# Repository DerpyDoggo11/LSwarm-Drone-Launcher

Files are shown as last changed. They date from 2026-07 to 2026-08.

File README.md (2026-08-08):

# LS Mk.1 Drone Launcher
Compact drone launcher + central compute module

## 3D Model Preview
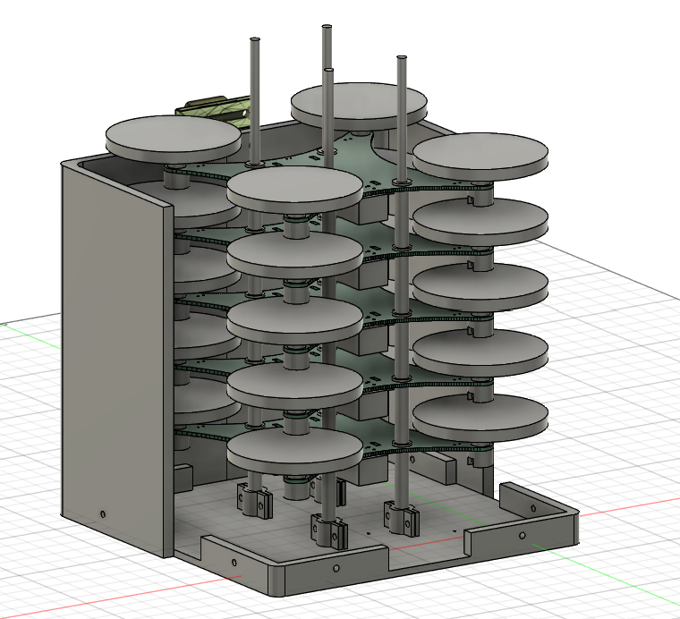
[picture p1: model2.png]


## 3D PCB Preview
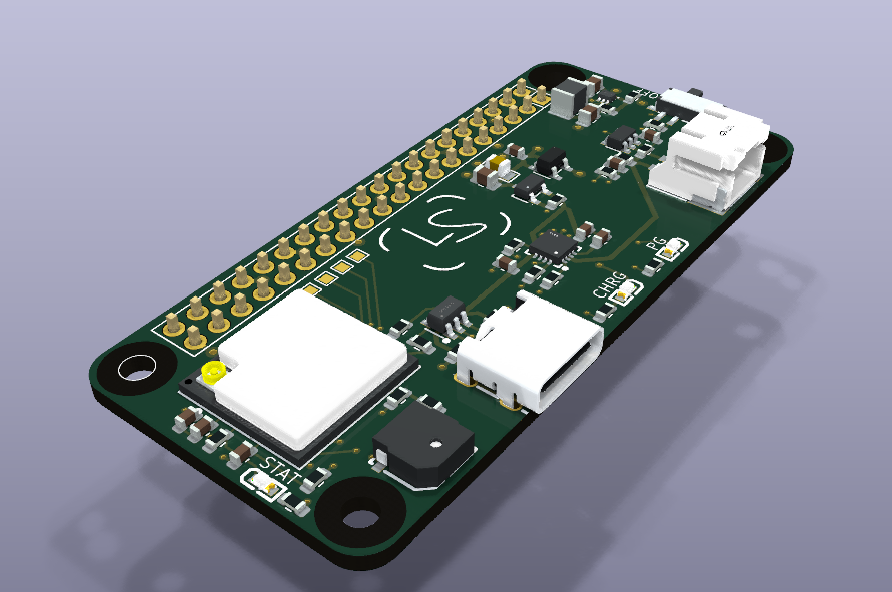
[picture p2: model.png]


## Wiring
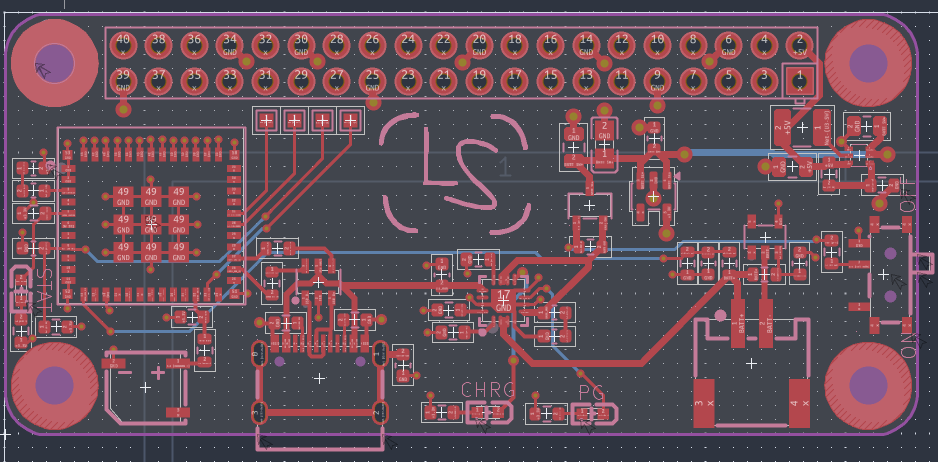
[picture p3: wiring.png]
PCB


## Schematic
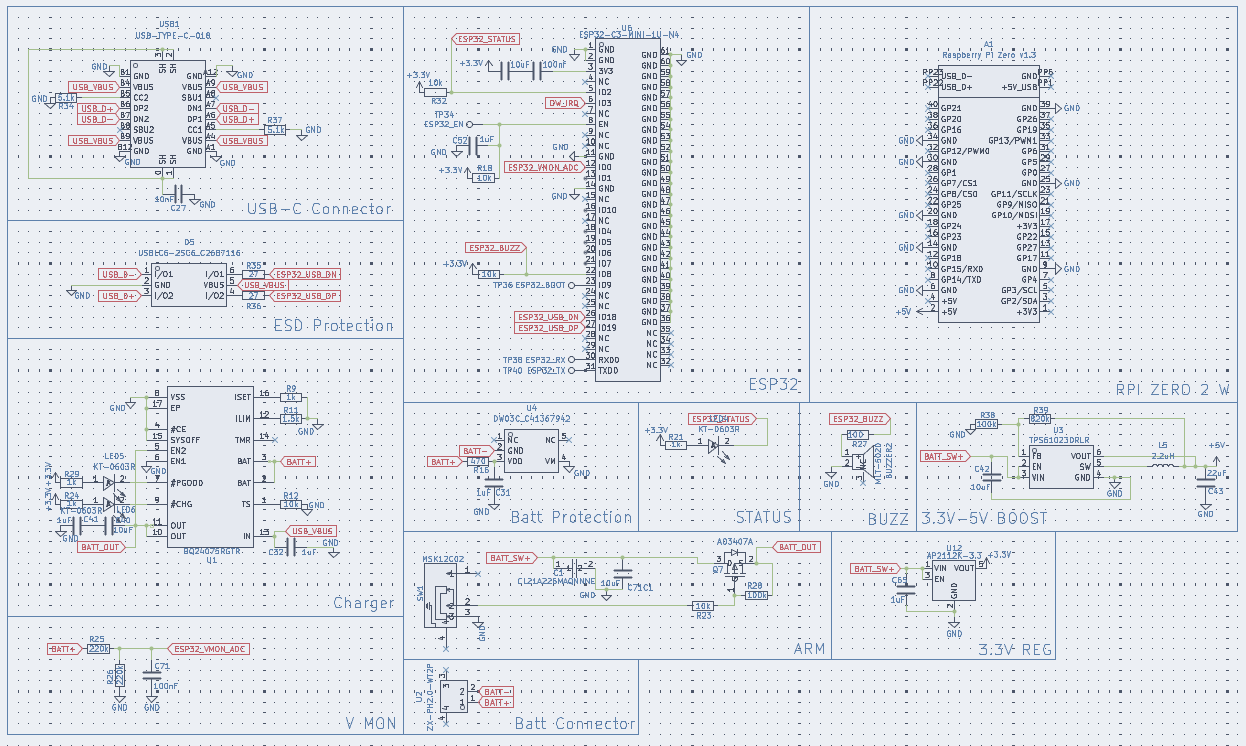
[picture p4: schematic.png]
Schematic


### Download ./latestProduction to begin fabricating the PCB

## Introduction
As a solution to needing to store tons of [these](https://forge.hackclub.com/projects/93) microdrones as well as the central compute unit, I designed a vertically mounting lift off platform and storage unit called the LS Mk.1 Drone Launcher. Its super modular so that it can be stacked on itself and easily stored in a grid and scale to any number of drones. The design is essentially a 3D printed platform with four metal rods for guiding the drones, the top and bottom half can separated or connected by opening or closing the latches. The platform currently has a capacity for 5 drones each.

For calculating and planning the trajectory of the drones, this launcher uses a Raspbbery Pi Zero 2 W along with a custom Pi hat. The custom Pi hat extends the wifi range of the Raspberry Pi Zero 2 W to communicate with the LS Anchors and adds a battery for independent usage from wall outlets. Only 1 compute module should be necessary per batch of launcher units.

## Bill of Materials 

### Minimum Build:

| Quantity | Components | Price | Link |
|--- |---|---| -----|
| 1  | Raspberry Pi Zero 2 W | ~15$ | [here](https://www.sparkfun.com/raspberry-pi-zero-2-w.html?src=raspberrypi)
| 1 | Clear PLA Filament | ~20$ | [here](https://www.amazon.com/SUNLU-Filament-Transparent-Dimensional-Accuracy/dp/B07ZNG4L9P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)
| 1 | 1200mAh Lipo Battery | ~20$ [here](https://www.aliexpress.us/item/3256811414820649.html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)
| 1 | 155mm Leather Handle | ~2$ | [here](https://www.aliexpress.us/item/3256812155687340.html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)
| 4 | 200mm x 4mm Metal Rods | $5 | [here](https://www.aliexpress.us/item/3256805290944526.html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)
| 1  | RPI Hat PCB | ~15$ | Download repo, extract fabrication files, and fabricate through JLCPCB (complete instructions for this may come soon)
| 1  | Electronic Components | ~30$ | See production BOM for a full list, the PCB fabrication files automatically include these components as well.
| 4 | 20mm M2.5 Bolts | $10 | Reference (can find it cheaper elsewhere): [here](https://www.mcmaster.com/products/91290a108/)
| 16 | 16mm M2.5 Bolts | $10 | Reference (can find it cheaper elsewhere): [here](https://www.mcmaster.com/products/91290A106/)
| 20 | M2.5 Nuts | $10 | Reference (can find it cheaper elsewhere): [here](https://www.mcmaster.com/products/90591a270/)

Total: ~$140

----

## Tools / Other parts:
- Hot air gun or hot plate
- Solder paste
- Tweazers
- Screwdriver

## Assembly
- Apply solder paste to all the solder pads
- Use tweazers to place components and reflow with hot air gun or hot plate
- Assemble control unit case and mount battery and antenna onto the pcb and raspbbery pi zero 2W
- Print all parts of the case
- Assemble the launcher case and latch together
- Print drone landing gears and mount them

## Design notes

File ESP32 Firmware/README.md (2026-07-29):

# ESP32-C3 Firmware — LSwarm Drone Launcher

Power/status co-processor that runs on the **ESP32-C3-MINI-1U-N4 (U6)** of the
Compute Hat. It measures the battery, watches the protection-IC fault line, and
drives the status LED and buzzer, exposing everything to the Raspberry Pi over
a USB-CDC line protocol.

## Hardware map (from the schematic)

| Function | GPIO | Notes |
|---|---|---|
| Status LED | 2 | Active-**low** (sinks from 3V3 via R21 1k). Boot strap. |
| DW03C fault | 3 | `DW_IRQ`, active-**low** input, internal pull-up. |
| Battery VMON  | 0 | ADC1_CH0, reads `BATT+ / 2` (R25 220k / R26 220k divider). |
| Buzzer | 8 | Active-**high**, MOSFET-driven MLT-5020, PWM tone. Strap. |
| Boot | 9 | Strap / test point — not driven by firmware. |

## Build / flash

```bash
pio run                 # build
pio run -t upload       # flash over the USB-C port
pio device monitor      # open the CDC serial monitor (115200)
```

## Link protocol

ASCII, one message per line (`\n`). Full definition in
[`include/protocol.h`](include/protocol.h) — kept identical to the Pi firmware.

**Pi → ESP32**

| Command | Effect |
|---|---|
| `PING` | replies `PONG` |
| `ID?` | replies `ID LSwarm-ESP32C3 fw=<ver>` |
| `STATUS?` | emits one `TELEM` frame immediately |
| `LED <mode>` | `off` `on` `blink` `beat` `sos` |
| `BUZZ <hz> <ms>` | play a tone for `<ms>` (`0` = stop) |
| `BEEP <count>` | N short feedback beeps |
| `TELEM <period_ms>`| set auto-telemetry period (`0` = off) |

**ESP32 → Pi**

| Message | When |
|---|---|
| `RDY <ver>` | once at boot |
| `TELEM v=<mV> soc=<pct> fault=<0/1> up=<ms>` | periodic / on `STATUS?` |
| `EVT fault=<0/1>` | on a DW_IRQ edge |
| `OK <cmd>` / `ERR <reason>` / `PONG` | command replies |

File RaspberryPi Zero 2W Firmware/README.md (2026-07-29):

# Raspberry Pi Zero 2 W Firmware — LSwarm Drone Launcher

The **central compute** node. The Pi Zero 2 W is a Linux SBC, so this is a
PlatformIO `native` C++ project written in the same Arduino `setup()`/`loop()`
style as the ESP32 firmware — a small Linux shim
([`include/arduino_compat.h`](include/arduino_compat.h)) provides `millis()`,
`delay()`, and a `Serial`-like port over the USB-CDC link.

Today it owns the link to the ESP32 co-processor (battery/fault telemetry,
LED/buzzer commands, keep-alive) and forwards operator input. Swarm / Wi-Fi
coordination logic builds on top of `loop()` in [`src/main.cpp`](src/main.cpp).

## How it connects

The ESP32-C3 native USB is shared with the Pi's USB-OTG lines on the USB-C
port, so the co-processor enumerates on the Pi as **`/dev/ttyACM0`**. The wire
protocol is defined in [`include/protocol.h`](include/protocol.h) (identical to
the ESP32's copy).

## Build & run

```bash
# On the Pi (or any Linux host), with PlatformIO Core:
pio run                                   # -> .pio/build/pizero/program
.pio/build/pizero/program                 # default: /dev/ttyACM0 @ 115200
.pio/build/pizero/program /dev/ttyACM1    # override port/baud

# Or straight from g++ if you'd rather skip PlatformIO:
g++ -std=c++17 -O2 -Iinclude src/*.cpp -o program
```

Add your user to the `dialout` group for serial access:
`sudo usermod -aG dialout $USER` (re-login after).

Run it as a service with the included [`lswarm-compute.service`](lswarm-compute.service).

## Using it

While running, type a command and press Enter — it goes straight to the ESP32:

```
LED blink          # status LED pattern: off | on | blink | beat | sos
BEEP 2             # two feedback beeps
BUZZ 2700 300      # 2.7 kHz tone for 300 ms
STATUS?            # request one telemetry frame
TELEM 500          # set auto-telemetry to 500 ms (0 = off)
quit               # exit
```

Incoming telemetry is printed live, e.g.
`[   12345] BATT 4013 mV  soc=79%  fault=0`.

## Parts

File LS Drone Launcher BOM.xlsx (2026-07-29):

Quantity | Component | Price | Link
1 | Raspberry Pi Zero 2W | $15 | https://www.sparkfun.com/raspberry-pi-zero-2-w.html?src=raspberrypi
1 | Clear PLA Filament | $20
1 | 1200mAh Lipo | $10 | https://www.aliexpress.us/item/3256811414820649.html?curPageLogUid=uhXJ9YqKgNaO
1 | 155mm Leather Handle | $2 | https://www.aliexpress.us/item/3256812155687340.html?curPageLogUid=BP5HyM53Apva
4 | 200mm x 4mm Metal Rods | $5 | https://www.aliexpress.us/item/3256805290944526.html?curPageLogUid=mLtoWIDfhah6
1 | Custom RPI Hat PCB | $15 | Download repo, extract fabrication files, and fabricate through JLCPCB (complete instructions for this may come soon)
1 | PCB Electronics | $30 | See production BOM for a full list, the PCB fabrication files automatically include these components as well.
Total | ~$100

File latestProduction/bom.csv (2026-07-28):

Designator | Footprint | Quantity | Value | LCSC Part #
A1 | RASPI_ZERO_FULL | 1 | Raspberry Pi Zero v1.3
BUZZER2 | BUZ-SMD_L5.0-W5.5-P4.60 | 1 | MLT-5020 | C94598
C1 | C0805 | 1 | CL21A226MAQNNNE | C45783
C27 | 0603 | 1 | 10nF
C31, C32, C41, C52, C65 | 0603 | 5 | 1uF
C40, C55 | 0603 | 2 | 10uF
C42, C71C1 | 0805 | 2 | 10uF
C43 | 0805 | 1 | 22uF
C56, C71 | 0603 | 2 | 100nf
D5 | SOT-23-6_L2.9-W1.6-P0.95-LS2.8-BL | 1 | USBLC6-2SC6_C2687116 | C2687116
L5 | 1210 | 1 | 2.2uH
LED4, LED5, LED6 | LED-SMD_L1.6-W0.8-R-RD | 3 | KT-0603R | C2286
Q7 | SOT-23-3_L2.9-W1.6-P1.90-LS2.8-BR | 1 | AO3407A | C15155
R11 | 0603 | 1 | 1.5k
R12, R18, R23, R32, R33 | 0603 | 5 | 10k
R16 | 0603 | 1 | 470
R21, R24, R29, R9 | 0603 | 4 | 1k
R25, R26 | 0603 | 2 | 220k
R27 | 0603 | 1 | 100
R28, R38 | 0603 | 2 | 100k
R34, R37 | 0603 | 2 | 5.1k
R35, R36 | 0603 | 2 | 27
R39 | 0603 | 1 | 820k
SW1 | SW-TH_MSK12C02 | 1 | MSK12C02 | C431540
TP34 | TestPoint_Pad_1.0x1.0mm | 1 | ESP32_EN
TP36 | TestPoint_Pad_1.0x1.0mm | 1 | ESP32_BOOT
TP38 | TestPoint_Pad_1.0x1.0mm | 1 | ESP32_RX
TP40 | TestPoint_Pad_1.0x1.0mm | 1 | ESP32_TX
U1 | QFN-16_L3.0-W3.0-P0.50-TL-EP1.7 | 1 | BQ24075RGTR | C15464
U12 | SOT-23-5 | 1 | AP2112K-3.3
U2 | CONN-SMD_ZX-PH2.0-WT2P | 1 | ZX-PH2.0-WT2P | C7429689
U3 | SOT-563_L1.6-W1.2-P0.50-LS1.6-BR | 1 | TPS61023DRLR | C919459
U4 | SOT-23-5_L2.9-W1.6-P0.95-LS2.9-BL | 1 | DW03C_C41367942 | C41367942
U6 | WIFIM-SMD_61P-L13.2-W12.5-P0.80 | 1 | ESP32-C3-MINI-1U-N4 | C2911374
USB1 | USB-C_SMD-TYPE-C-31-M-12 | 1 | USB-TYPE-C-018 | C2927038

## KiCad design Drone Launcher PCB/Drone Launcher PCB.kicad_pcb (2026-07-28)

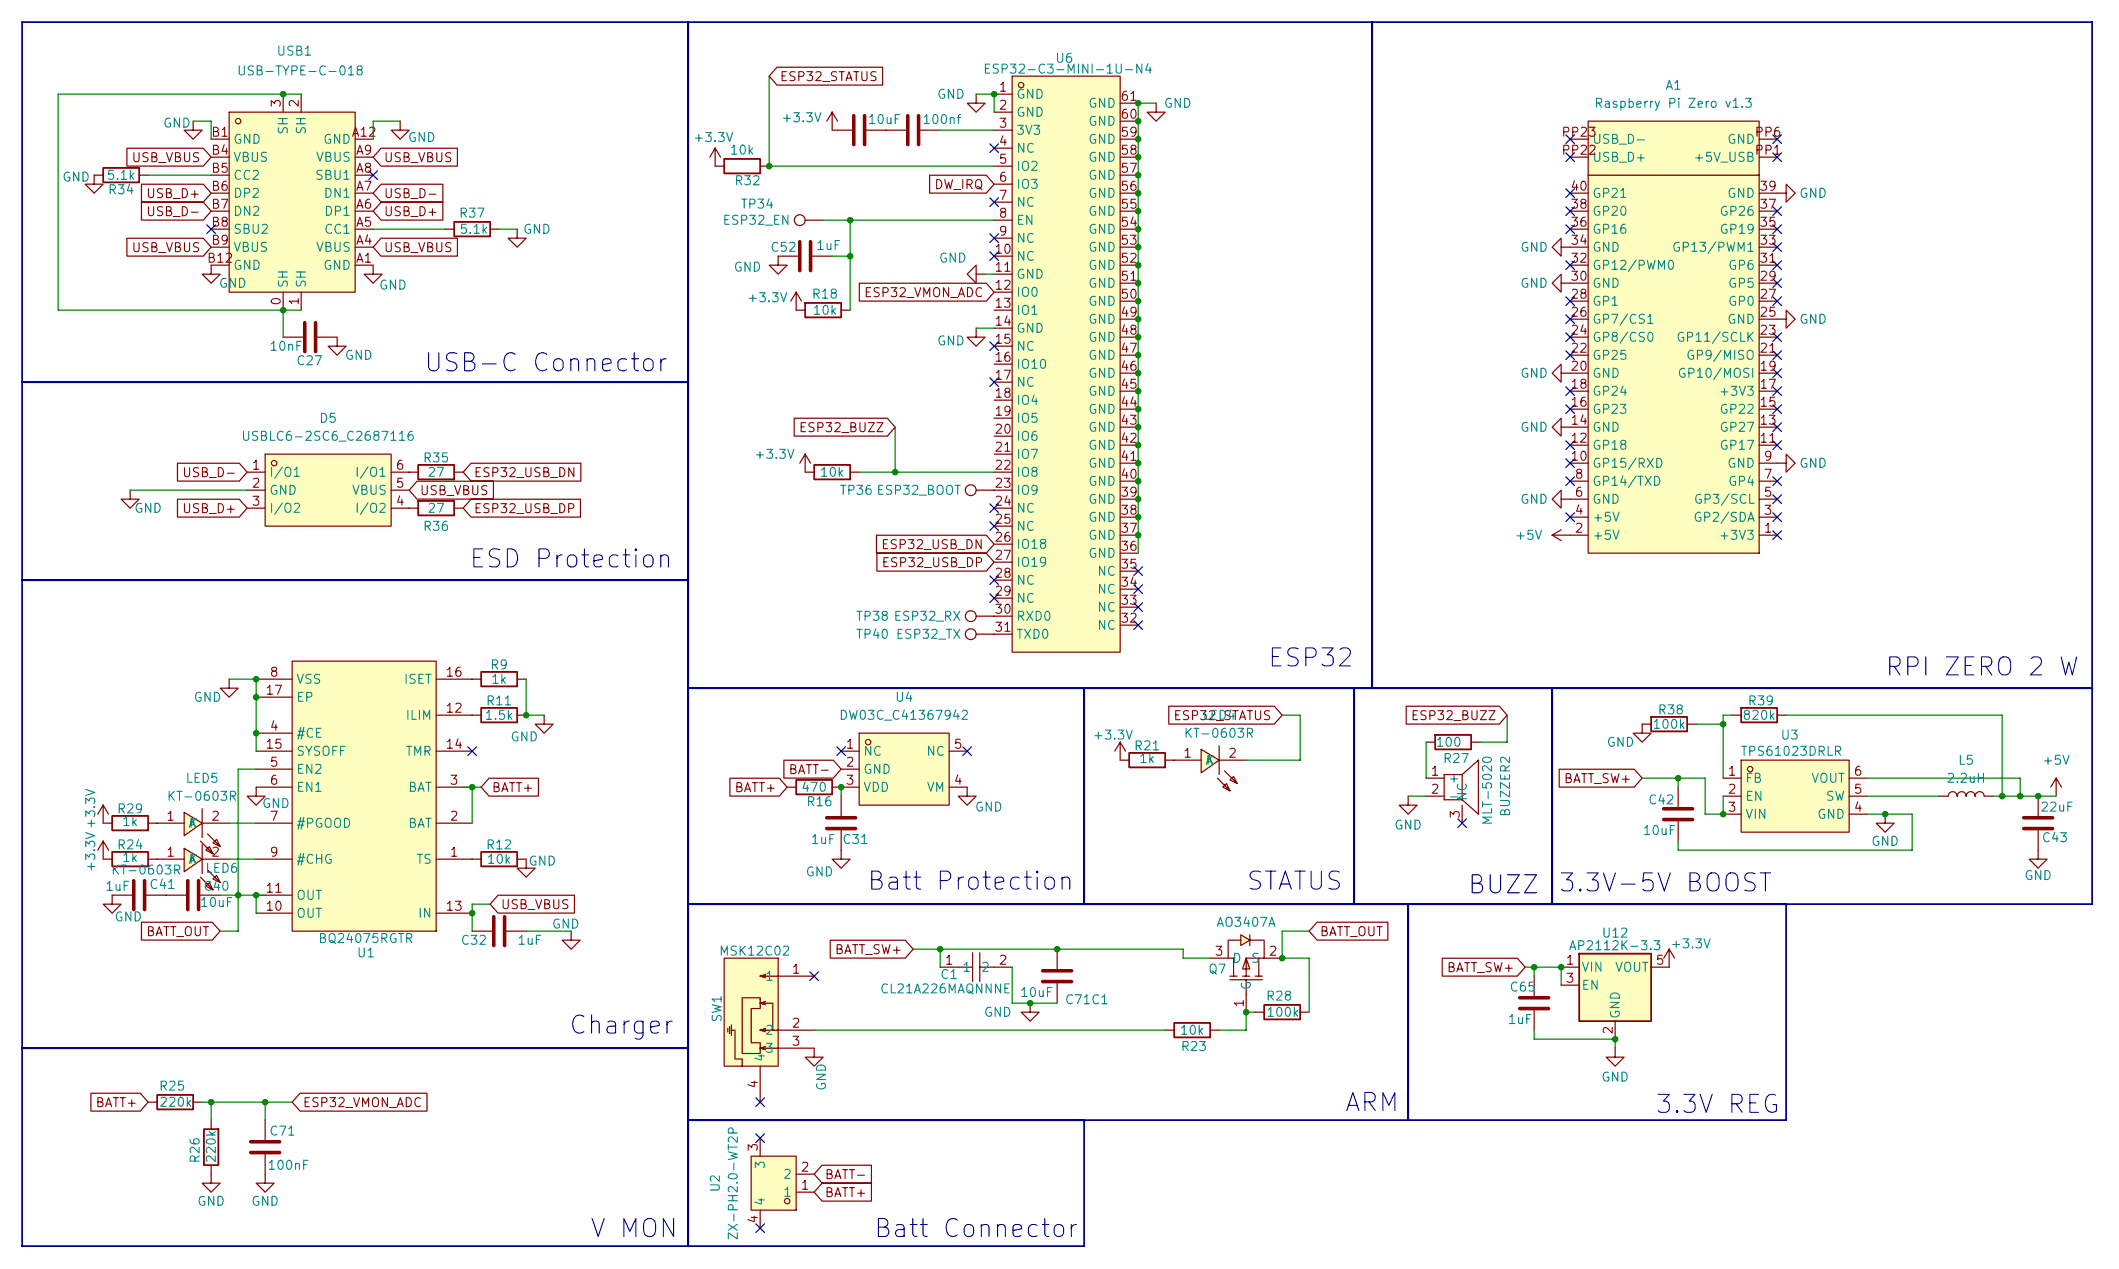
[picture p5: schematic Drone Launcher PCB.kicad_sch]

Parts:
A1: Raspberry Pi Zero v1.3; RASPI_ZERO_FULL
BUZZER2: MLT-5020; BUZ-SMD_L5.0-W5.5-P4.60; MPN MLT-5020; LCSC Part C94598
C1: CL21A226MAQNNNE; C0805; MPN CL21A226MAQNNNE; LCSC Part C45783
C27: 10nF; C_0603_1608Metric
C31, C32, C41, C52, C65: 1uF; C_0603_1608Metric
C40, C55: 10uF; C_0603_1608Metric
C42, C71C1: 10uF; C_0805_2012Metric
C43: 22uF; C_0805_2012Metric
C56: 100nf; C_0603_1608Metric
C71: 100nF; C_0603_1608Metric
D5: USBLC6-2SC6_C2687116; SOT-23-6_L2.9-W1.6-P0.95-LS2.8-BL; MPN USBLC6-2SC6; LCSC Part C2687116
L5: 2.2uH; L_1210_3225Metric
LED4, LED5, LED6: KT-0603R; LED-SMD_L1.6-W0.8-R-RD; MPN KT-0603R; LCSC Part C2286
Q7: AO3407A; SOT-23-3_L2.9-W1.6-P1.90-LS2.8-BR; MPN AO3407A; LCSC Part C15155
R9, R21, R24, R29: 1k; R_0603_1608Metric
R11: 1.5k; R_0603_1608Metric
R12, R18, R23, R32, R33: 10k; R_0603_1608Metric
R16: 470; R_0603_1608Metric
R25, R26: 220k; R_0603_1608Metric
R27: 100; R_0603_1608Metric
R28, R38: 100k; R_0603_1608Metric
R34, R37: 5.1k; R_0603_1608Metric
R35, R36: 27; R_0603_1608Metric
R39: 820k; R_0603_1608Metric
SW1: MSK12C02; SW-TH_MSK12C02; MPN MSK12C02; LCSC Part C431540
TP34: ESP32_EN; TestPoint_Pad_1.0x1.0mm
TP36: ESP32_BOOT; TestPoint_Pad_1.0x1.0mm
TP38: ESP32_RX; TestPoint_Pad_1.0x1.0mm
TP40: ESP32_TX; TestPoint_Pad_1.0x1.0mm
U1: BQ24075RGTR; QFN-16_L3.0-W3.0-P0.50-TL-EP1.7; MPN BQ24075RGTR; LCSC Part C15464
U2: ZX-PH2.0-WT2P; CONN-SMD_ZX-PH2.0-WT2P; MPN ZX-PH2.0-WT2P; LCSC Part C7429689
U3: TPS61023DRLR; SOT-563_L1.6-W1.2-P0.50-LS1.6-BR; MPN TPS61023DRLR; LCSC Part C919459
U4: DW03C_C41367942; SOT-23-5_L2.9-W1.6-P0.95-LS2.9-BL; MPN DW03C; LCSC Part C41367942
U6: ESP32-C3-MINI-1U-N4; WIFIM-SMD_61P-L13.2-W12.5-P0.80; MPN ESP32-C3-MINI-1U-N4; LCSC Part C2911374
U12: AP2112K-3.3; SOT-23-5
USB1: USB-TYPE-C-018; USB-C_SMD-TYPE-C-31-M-12; MPN USB-TYPE-C-018; LCSC Part C2927038

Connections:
+3.3V: C55.2, R18.2, R21.1, R24.1, R29.1, R32.1, R33.1, U12.5 (VOUT)
+5V: A1.2 (+5V), C43.2, L5.2, R39.1, U3.6 (VOUT)
BATT+: R16.1, R25.1, U1.2 (BAT), U1.3 (BAT), U2.1
BATT-: U2.2, U4.2 (GND)
BATT_OUT: C40.1, Q7.2 (S), R28.2, U1.5 (EN2), U1.10 (OUT), U1.11 (OUT)
BATT_SW+: C1.1, C42.1, C65.2, C71C1.2, Q7.3 (D), U3.2 (EN), U3.3 (VIN), U12.1 (VIN), U12.3 (EN)
DW_IRQ: U6.6 (IO3)
ESP32_BUZZ: R27.1, R33.2, U6.22 (IO8)
ESP32_STATUS: LED4.2 (K), R32.2, U6.5 (IO2)
ESP32_USB_DN: R35.2, U6.26 (IO18)
ESP32_USB_DP: R36.1, U6.27 (IO19)
ESP32_VMON_ADC: C71.2, R25.2, R26.2, U6.12 (IO0)
GND: A1.6 (GND), A1.9 (GND), A1.14 (GND), A1.20 (GND), A1.25 (GND), A1.30 (GND), A1.34 (GND), A1.39 (GND), BUZZER2.2 (-), C1.2, C27.1, C31.2, C32.1, C41.1, C42.2, C43.1, C52.1, C65.1, C71.1, C71C1.1, D5.2 (GND), R9.2, R11.2, R12.2, R26.1, R34.1, R37.2, R38.2, SW1.3, U1.4 (#CE), U1.6 (EN1), U1.8 (VSS), U1.15 (SYSOFF), U1.17 (EP), U3.4 (GND), U4.4 (VM), U6.1 (GND), U6.2 (GND), U6.11 (GND), U6.14 (GND), U6.36 (GND), U6.37 (GND), U6.38 (GND), U6.39 (GND), U6.40 (GND), U6.41 (GND), U6.42 (GND), U6.43 (GND), U6.44 (GND), U6.45 (GND), U6.46 (GND), U6.47 (GND), U6.48 (GND), U6.49 (GND), U6.50 (GND), U6.51 (GND), U6.52 (GND), U6.53 (GND), U6.54 (GND), U6.55 (GND), U6.56 (GND), U6.57 (GND), U6.58 (GND), U6.59 (GND), U6.60 (GND), U6.61 (GND), U12.2 (GND), USB1.A1 (GND), USB1.A12 (GND), USB1.B1 (GND), USB1.B12 (GND)
unnamed: BUZZER2.1 (+), R27.2
unnamed: C27.2, USB1.0 (SH), USB1.1 (SH), USB1.2 (SH), USB1.3 (SH)
unnamed: C40.2, C41.2
unnamed: C55.1, C56.2
unnamed: D5.6 (I/O1), R35.1
unnamed: D5.4 (I/O2), R36.2
unnamed: LED4.1 (A), R21.2
unnamed: LED5.1 (A), R29.2
unnamed: LED5.2 (K), U1.7 (#PGOOD)
unnamed: LED6.1 (A), R24.2
unnamed: LED6.2 (K), U1.9 (#CHG)
unnamed: Q7.1 (G), R23.2, R28.1
unnamed: R23.1, SW1.2
unnamed: R11.1, U1.12 (ILIM)
unnamed: R9.1, U1.16 (ISET)
unnamed: R12.1, U1.1 (TS)
unnamed: R38.1, R39.2, U3.1 (FB)
unnamed: L5.1, U3.5 (SW)
unnamed: C31.1, R16.2, U4.3 (VDD)
unnamed: C56.1, U6.3 (3V3)
unnamed: C52.2, R18.1, TP34.1 (1_1), U6.8 (EN)
unnamed: TP36.1 (1_1), U6.23 (IO9)
unnamed: TP38.1 (1_1), U6.30 (RXD0)
unnamed: TP40.1 (1_1), U6.31 (TXD0)
unnamed: R37.1, USB1.A5 (CC1)
unnamed: R34.2, USB1.B5 (CC2)
USB_D+: D5.3 (I/O2), USB1.A6 (DP1), USB1.B6 (DP2)
USB_D-: D5.1 (I/O1), USB1.A7 (DN1), USB1.B7 (DN2)
USB_VBUS: C32.2, D5.5 (VBUS), U1.13 (IN), USB1.A4 (VBUS), USB1.A9 (VBUS), USB1.B4 (VBUS), USB1.B9 (VBUS)

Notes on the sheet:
BUZZ
V MON
STATUS
RPI ZERO 2 W
ARM
USB-C Connector
3.3V REG
Batt Connector
ESP32
ESD Protection
3.3V-5V BOOST
Charger
Batt Protection

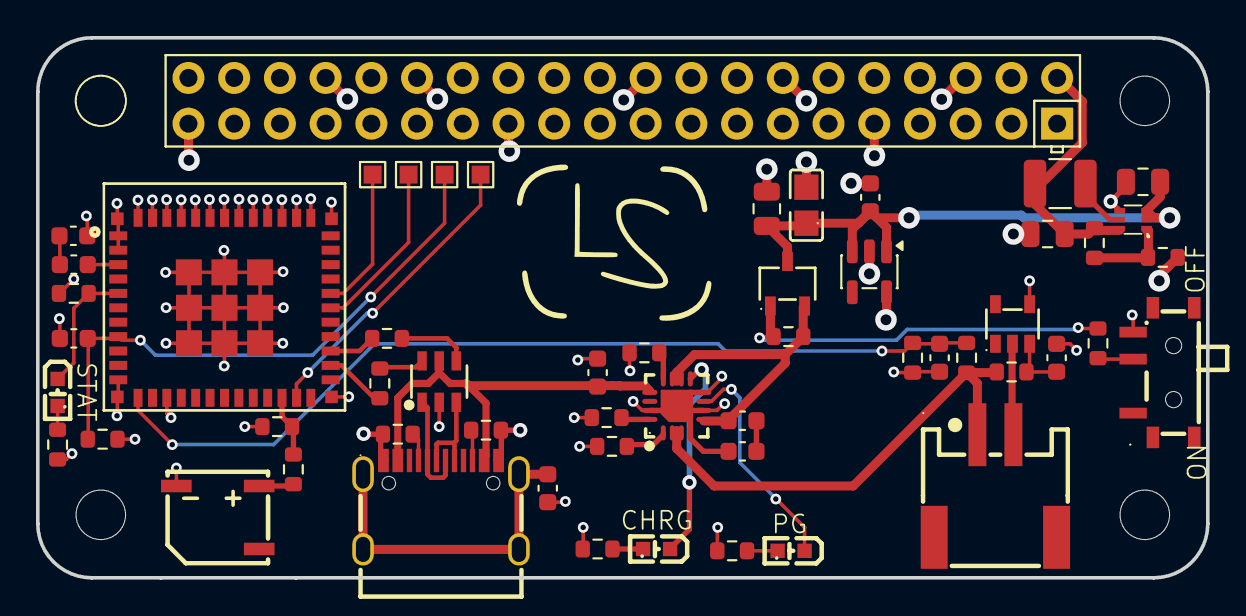
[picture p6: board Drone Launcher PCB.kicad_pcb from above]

Board: 4 copper layers, 65.0 x 30.0 mm, 55 parts (0 on the bottom side), 41 nets.

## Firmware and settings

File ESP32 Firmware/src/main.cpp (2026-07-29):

#include <Arduino.h>
#include "pins.h"
#include "protocol.h"

#if ESP_ARDUINO_VERSION_MAJOR >= 3
static void buzzerBegin() { ledcAttach(PIN_BUZZER, 2700, 10); ledcWrite(PIN_BUZZER, 0); }
static void buzzerTone(uint32_t f) { if (f) ledcWriteTone(PIN_BUZZER, f); else ledcWrite(PIN_BUZZER, 0); }
#else
static const uint8_t BUZ_CH = 0;
static void buzzerBegin() { ledcSetup(BUZ_CH, 2700, 10); ledcAttachPin(PIN_BUZZER, BUZ_CH); ledcWrite(BUZ_CH, 0); }
static void buzzerTone(uint32_t f) { if (f) ledcWriteTone(BUZ_CH, f); else ledcWrite(BUZ_CH, 0); }
#endif

static uint32_t buzzEndMs = 0;
static uint8_t beepsLeft = 0;
static bool beepOn = false;
static uint32_t beepNextMs = 0;

static void buzzStart(uint32_t freq, uint32_t ms) {
  buzzerTone(freq);
  buzzEndMs = (freq && ms) ? millis() + ms : 0;
  if (!buzzEndMs) buzzerTone(0);
}

static void beepStart(uint8_t count) {
  beepsLeft = count;
  beepOn = false;
  beepNextMs = millis();
}

enum LedMode { LED_OFF, LED_ON, LED_BLINK, LED_BEAT, LED_SOS };
static LedMode ledMode = LED_BEAT;

static inline void ledWrite(bool on) { digitalWrite(PIN_STATUS_LED, on ? LOW : HIGH); }

static const uint16_t SOS_PATTERN[] = {
  200, 200, 200, 200, 200, 600,
  600, 200, 600, 200, 600, 600,
  200, 200, 200, 200, 200, 1400
};

static uint8_t sosIdx = 0;
static bool sosOn = false;
static uint32_t sosNext = 0;

static void ledTask() {
  const uint32_t now = millis();
  switch (ledMode) {
    case LED_OFF: ledWrite(false); break;
    case LED_ON: ledWrite(true); break;
    case LED_BLINK: {
      ledWrite((now / 250) & 1);
      break;
    }
    case LED_BEAT: {
      uint32_t t = now % 1200;
      ledWrite(t < 90 || (t >= 200 && t < 290));
      break;
    }
    case LED_SOS: {
      if (now >= sosNext) {
        sosOn = !sosOn;
        ledWrite(sosOn);
        sosNext = now + SOS_PATTERN[sosIdx];
        sosIdx = (sosIdx + 1) % (sizeof(SOS_PATTERN) / sizeof(SOS_PATTERN[0]));
      }
      break;
    }
  }
}

static void setLed(const String &m) {
  if (m == "off") ledMode = LED_OFF;
  else if (m == "on") ledMode = LED_ON;
  else if (m == "blink") ledMode = LED_BLINK;
  else if (m == "beat") ledMode = LED_BEAT;
  else if (m == "sos") { ledMode = LED_SOS; sosIdx = 0; sosOn = false; sosNext = 0; }
}

static uint32_t readBatt_mV() {
  uint32_t acc = 0;
  for (int i = 0; i < 8; i++) acc += analogReadMilliVolts(PIN_VMON_ADC);
  uint32_t vadc = acc / 8;
  return (uint32_t)((uint64_t)vadc * LSWARM_VDIV_NUM / LSWARM_VDIV_DEN);
}

static uint8_t soc_pct(uint32_t mV) {
  if (mV <= LSWARM_BATT_EMPTY_MV) return 0;
  if (mV >= LSWARM_BATT_FULL_MV) return 100;
  return (uint8_t)((mV - LSWARM_BATT_EMPTY_MV) * 100UL / (LSWARM_BATT_FULL_MV - LSWARM_BATT_EMPTY_MV));
}

static bool faultActive() { return digitalRead(PIN_DW_IRQ) == LOW; }

static void sendTelemetry() {
  uint32_t mV = readBatt_mV();
  Serial.printf("%s v=%u soc=%u fault=%u up=%lu\n", RSP_TELEM, mV, soc_pct(mV), faultActive() ? 1 : 0, (unsigned long)millis());
}

static void handleLine(String line) {
  line.trim();
  if (line.length() == 0) return;

  int sp = line.indexOf(' ');
  String cmd = (sp < 0) ? line : line.substring(0, sp);
  String arg = (sp < 0) ? "" : line.substring(sp + 1);
  arg.trim();

  if (cmd == CMD_PING) {
    Serial.println(RSP_PONG);
  } else if (cmd == CMD_ID) {
    Serial.printf("%s %s fw=%s\n", RSP_ID, LSWARM_DEV_NAME, LSWARM_FW_VERSION);
  } else if (cmd == CMD_STATUS) {
    sendTelemetry();
  } else if (cmd == CMD_LED) {
    setLed(arg);
    Serial.printf("%s %s\n", RSP_OK, line.c_str());
  } else if (cmd == CMD_BUZZ) {
    int sp2 = arg.indexOf(' ');
    uint32_t f = arg.toInt();
    uint32_t ms = (sp2 < 0) ? 0 : (uint32_t)arg.substring(sp2 + 1).toInt();
    buzzStart(f, ms);
    Serial.printf("%s %s\n", RSP_OK, line.c_str());
  } else if (cmd == CMD_BEEP) {
    beepStart((uint8_t)constrain(arg.toInt(), 1, 20));
    Serial.printf("%s %s\n", RSP_OK, line.c_str());
  } else if (cmd == CMD_TELEM) {
    Serial.printf("%s %s\n", RSP_OK, line.c_str());
  } else {
    Serial.printf("%s unknown:%s\n", RSP_ERR, cmd.c_str());
    return;
  }
}

static uint32_t telemPeriod = LSWARM_TELEM_MS;

static void maybeHandleTelemPeriod(const String &line) {
  if (line.startsWith(CMD_TELEM)) {
    int sp = line.indexOf(' ');
    if (sp > 0) telemPeriod = (uint32_t)line.substring(sp + 1).toInt();
  }
}

static char lineBuf[LSWARM_LINE_MAX];
static uint8_t lineLen = 0;

static void serialTask() {
  while (Serial.available()) {
    char c = (char)Serial.read();
    if (c == '\n' || c == '\r') {
      if (lineLen) {
        lineBuf[lineLen] = '\0';
        String line(lineBuf);
        maybeHandleTelemPeriod(line);
        handleLine(line);
        lineLen = 0;
      }
    } else if (lineLen < LSWARM_LINE_MAX - 1) {
      lineBuf[lineLen++] = c;
    } else {
      lineLen = 0;
    }
  }
}

void setup() {
  pinMode(PIN_STATUS_LED, OUTPUT);
  ledWrite(false);
  pinMode(PIN_DW_IRQ, INPUT_PULLUP);
  analogReadResolution(12);
  buzzerBegin();

  Serial.begin(LSWARM_LINK_BAUD);
  delay(50);
  Serial.printf("%s %s\n", RSP_READY, LSWARM_FW_VERSION);
}

void loop() {
  const uint32_t now = millis();

  serialTask();
  ledTask();

  if (buzzEndMs && now >= buzzEndMs) { buzzerTone(0); buzzEndMs = 0; }
  if (beepsLeft && now >= beepNextMs) {
    beepOn = !beepOn;
    buzzerTone(beepOn ? 2700 : 0);
    beepNextMs = now + 80;
    if (!beepOn) beepsLeft--;
  }

  static uint32_t lastTelem = 0;
  if (telemPeriod && now - lastTelem >= telemPeriod) { lastTelem = now; sendTelemetry(); }

  static int lastFault = -1;
  int f = faultActive() ? 1 : 0;
  if (f != lastFault) {
    lastFault = f;
    Serial.printf("%s fault=%d\n", RSP_EVENT, f);
    if (f) beepStart(3);
  }
}

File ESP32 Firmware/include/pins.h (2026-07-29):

#pragma once

#define PIN_STATUS_LED 2
#define PIN_DW_IRQ 3
#define PIN_VMON_ADC 0
#define PIN_BUZZER 8
#define PIN_BOOT 9

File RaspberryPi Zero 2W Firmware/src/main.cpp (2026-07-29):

#include <cstdio>
#include <cstdlib>
#include <cstring>
#include <string>
#include <csignal>

#include "arduino_compat.h"
#include "protocol.h"

static std::string g_port = "/dev/ttyACM0";
static int g_baud = LSWARM_LINK_BAUD;

static SerialPort link;
static bool g_linkUp = false;
static uint32_t g_lastRxMs = 0;
static uint32_t g_lastPingMs = 0;
static uint32_t g_lastBattMv = 0;
static int g_soc = -1;
static int g_fault = 0;

static const uint32_t LINK_TIMEOUT_MS = 4000;
static const uint32_t PING_PERIOD_MS = 3000;

static volatile sig_atomic_t g_run = 1;
static void onSig(int) { g_run = 0; }

static void logLine(const char *tag, const std::string &s) {
  printf("[%8u] %-4s %s\n", millis(), tag, s.c_str());
  fflush(stdout);
}

static bool getKV(const std::string &s, const char *key, long &val) {
  std::string pat = std::string(" ") + key + "=";
  std::string hay = " " + s;
  size_t p = hay.find(pat);
  if (p == std::string::npos) return false;
  val = strtol(hay.c_str() + p + pat.size(), nullptr, 10);
  return true;
}

static void onTelemetry(const std::string &line) {
  long v = 0, soc = 0, fault = 0;
  getKV(line, "v", v);
  getKV(line, "soc", soc);
  getKV(line, "fault", fault);
  g_lastBattMv = (uint32_t)v;
  g_soc = (int)soc;
  g_fault = (int)fault;
}

static void onLinkMessage(const std::string &line) {
  g_lastRxMs = millis();

  if (line.rfind(RSP_READY, 0) == 0) {
    logLine("ESP", ("co-processor ready: " + line).c_str());
    link.println(std::string(CMD_ID));
    link.println(std::string(CMD_TELEM) + " " + std::to_string(LSWARM_TELEM_MS));
    return;
  }
  if (line.rfind(RSP_TELEM, 0) == 0) {
    onTelemetry(line);
    printf("[%8u] BATT %u mV  soc=%d%%  fault=%d\n", millis(), g_lastBattMv, g_soc, g_fault);
    fflush(stdout);
    return;
  }
  if (line.rfind(RSP_EVENT, 0) == 0) {
    logLine("EVT", line);
    long f = 0;
    getKV(line, "fault", f);
    if (f) logLine("WARN", "battery-protection FAULT");
    return;
  }
  logLine("ESP", line);
}

void setup() {
  console::init();
  printf("LSwarm Pi compute  fw=%s  port=%s @ %d\n", LSWARM_FW_VERSION, g_port.c_str(), g_baud);
  printf("Type commands (e.g. 'LED blink', 'BEEP 2', 'STATUS?') and press Enter.\n");
  fflush(stdout);
}

void loop() {
  const uint32_t now = millis();

  if (!link.isOpen()) {
    if (link.ensureOpen(g_port.c_str(), g_baud)) {
      logLine("LINK", "opened " + g_port);
      g_linkUp = false;
      g_lastRxMs = now;
    } else {
      delay(500);
      return;
    }
  }

  std::string line;
  while (link.readLine(line)) onLinkMessage(line);
  if (!link.isOpen()) {
    logLine("LINK", "lost, will reconnect");
    g_linkUp = false;
    return;
  }

  std::string cmd;
  while (console::readLine(cmd)) {
    if (cmd == "quit" || cmd == "exit") { g_run = 0; return; }
    link.println(cmd);
  }

  if (now - g_lastPingMs >= PING_PERIOD_MS) { g_lastPingMs = now; link.println(std::string(CMD_PING)); }

  bool up = (now - g_lastRxMs) < LINK_TIMEOUT_MS;
  if (up != g_linkUp) {
    g_linkUp = up;
    logLine("LINK", up ? "co-processor online" : "co-processor STALE (no telemetry)");
  }

  delay(5);
}

int main(int argc, char **argv) {
  if (argc > 1) g_port = argv[1];
  if (argc > 2) g_baud = atoi(argv[2]);

  signal(SIGINT, onSig);
  signal(SIGTERM, onSig);

  setup();
  while (g_run) loop();

  link.end();
  printf("\nshutting down.\n");
  return 0;
}
